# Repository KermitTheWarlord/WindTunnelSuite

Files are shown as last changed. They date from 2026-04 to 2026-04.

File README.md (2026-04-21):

# WindTunnelSuite

Control and monitoring system for a small educational wind tunnel built around **Arduino** and a **Windows Forms PC application**.

This project combines:

- a physical wind tunnel prototype
- Arduino firmware for sensors, fans, lighting, and airfoil-angle control
- a Windows desktop UI for live control and telemetry
- KiCad schematic files
- 3D printed mechanical parts for the enclosure, tunnel sections, venturi iterations, and smoke-flow visualization parts

---

## Project purpose

The goal of this project is to create a **modular and understandable wind tunnel system** suitable for:

- school demonstrations
- basic aerodynamic experiments
- testing airflow behavior around an airfoil
- learning embedded control, sensors, PWM, serial communication, and PC-side visualization

The current implementation is intentionally built at **educational / demonstrational scale**.  
The present fan solution uses **4 smaller fans** as a modular temporary approach, but the design can be adapted later to a **single larger high-flow fan**.

---

## Main features

### Arduino side
- PWM control of multiple fans
- control of airfoil angle through a stepper motor and A4988 driver
- angle feedback with AS5600 magnetic encoder
- barometric pressure and temperature measurement
- differential pressure measurement for airflow-related testing
- serial command parser for communication with the PC app
- telemetry output back to the PC application
- EEPROM storage for encoder zero / home behavior

### PC application side
- serial COM port connection
- separate UI pages for:
  - fan control
  - sensor live data
  - airfoil angle control
- live telemetry parsing
- console log for TX/RX debugging
- visual organization of controls for easy demonstration use

### Mechanical side
- 3D printed wind tunnel body and sections
- two physical design directions / configurations were used during development:
  - larger concept around **540 x 540 mm** inlet class
  - smaller demonstrational configuration around **240 x 240 mm** for use with PC fans
- venturi development through multiple printed variants
- smoke injector and holder for visual airflow observation
- printed enclosure / holder components for electronics and mounting

---

## Repository contents

Typical contents in this repository include:

- Arduino sketch / firmware
- Windows Forms solution
- KiCad schematic files
- schematic export PDF
- 3D model files (`.3mf`)
- supporting documentation and project assets

Important project files include:

- `WTS_Arduino_Sketch.ino` – Arduino firmware
- `WindTunnelSuite.sln` – Visual Studio solution
- `Arduino LED Blinker/WindTunnelSuite.csproj` – WinForms project
- `Arduino LED Blinker/Form1.cs` – main shell / navigation / serial handling
- `Arduino LED Blinker/FansPage.xaml.cs` – fan control page
- `Arduino LED Blinker/SensorsPage.xaml.cs` – live sensor page
- `Arduino LED Blinker/AirfoilAnglePage.cs` – airfoil angle control page
- `Arduino LED Blinker/TelemetryStore.cs` – telemetry parser / storage
- KiCad files for the electrical design
- `.3mf` files for the mechanical parts

---

## Hardware overview

### Main controller
- **Arduino Uno**  
Chosen because it is widely available, easy to program, well documented, and fully adequate for a school-scale control system.

### Sensors
- **AS5600 magnetic encoder**  
Used to measure the real angular position of the airfoil mechanism.

- **MPXV7002 differential pressure sensor**  
Used for airflow / pressure-difference observation in the test section.

- **BMP sensor module**  
The project wiring was prepared so the connector can support a **BMP280-style module**, while the current code path can also work with a **BMP180/BMP085-type module** because only the required **3.3 V, GND, SDA, and SCL** lines are needed in this operating mode.

### Actuators
- **A4988 stepper driver + NEMA 17 stepper motor**  
Used to rotate and position the airfoil.

- **4 fans**  
Used in the current prototype for demonstrational airflow generation. This is a modular starter solution.

- **LED lighting via MOSFET**  
Used for visual illumination of the test area.

### Protection / support components
- fuse on the AC input side
- onboard / supply-side protection
- filter / buffer capacitors
- gate resistor and pull-down resistor for MOSFET-based switching
- common ground strategy for correct signal reference

### Capacitors
Capacitors in the system are used mainly as **parallel filtering and buffering elements** on the supply rails.  
Their role is to:
- reduce voltage dips
- smooth disturbances caused by switching loads
- improve stability when motors, fans, or other loads change state

Examples used in the project documentation:
- **1000 µF / 25 V**
- **100 µF / 25 V**

---

## Electrical connection summary

### I2C bus
The I2C sensor modules are connected **in parallel** to the same:
- SDA line
- SCL line
- 3.3 V supply
- ground

This is normal I2C bus wiring and allows multiple compatible devices on the same bus.

### Fans
The fans are powered as **parallel loads** from the common supply, while their control is handled through PWM-related circuitry / control outputs.

### LED lighting
The LED lighting is treated as a **parallel-powered load** controlled through a MOSFET switching stage.

### AC input path
The AC switch and fuse are connected **in series** in the mains input path so that:
- the switch can disconnect power
- the fuse can interrupt the circuit in fault conditions

### Potentiometer
The potentiometer is used as a **voltage divider**.  
Its output is read by an Arduino analog input and converted into a control value.

---

## Software architecture

### Arduino firmware
The firmware is structured around several responsibilities:

- reading commands from serial
- controlling fans
- controlling the stepper motor
- reading sensors
- outputting telemetry
- managing home / zero logic for the encoder

Typical command ideas used by the PC app include:

- `FAN ALL <value>`
- `FAN 1 <value>`
- `FAN 2 <value>`
- `FAN 3 <value>`
- `FAN 4 <value>`
- `FAN STOP`
- `STEPPER GOTO <steps> <speed>`
- `STEPPER STOP`
- `ENCODER ZERO`

Telemetry is sent back in a compact key-value style so the desktop app can parse and display live values.

### Notes
- In the current development stage, some RPM values shown in the software can be **simulated from PWM percentage** instead of coming from real tachometer feedback.
- Telemetry names may reflect earlier naming choices; for example a field like `mpx_adc` may actually represent a processed pressure-related value in software rather than a raw ADC count.

### Windows Forms application

The desktop software is built with **C# Windows Forms**.

#### Main responsibilities
- connect to Arduino through a COM port
- send user commands
- parse incoming telemetry
- display live values
- show a TX/RX console for debugging

#### Main pages

**Fans page**  
Used to control:
- all fans together
- each fan individually

It also displays RPM-style feedback values for demonstration.

**Sensors page**  
Displays live readings such as:
- last packet received
- fan-related values
- differential pressure
- barometric pressure
- temperature
- encoder angle

**Airfoil Angle page**  
Used to:
- set target angle
- control movement speed
- stop motion
- home the mechanism
- zero the encoder reference

#### UI helper components
A custom `GlassPanel` is used to give the interface a cleaner demonstrational layout.

---

## Libraries

The exact Arduino libraries may depend on the current firmware revision, but the project uses or has used libraries in this area:

- `Wire`
- `EEPROM`
- `AccelStepper`
- Adafruit BMP sensor library path such as:
  - `Adafruit_BMP085` for BMP180/BMP085-style support

Check the `.ino` file for the exact current include list used in the active version.

---

## Real-world testing

The project has been physically tested and documented with:

- real hardware prototype photos
- oscilloscope captures of fan PWM behavior
- fan PWM duty-cycle checks
- sensor checks
- repeated startup / restart behavior
- stepper movement evaluation
- physical airfoil positioning

Oscilloscope photos in the project/documentation correspond to **fan PWM testing** at different duty cycles such as:
- 0%
- 25%
- 50%
- 75%
- 100%

---

## How to build / run

### Arduino
1. Open the Arduino sketch.
2. Install the required libraries.
3. Select the correct board and COM port.
4. Upload the firmware to the Arduino.

### Windows app
1. Open `WindTunnelSuite.sln` in Visual Studio.
2. Build the solution.
3. Run the WinForms application.
4. Select the correct COM port.
5. Connect and begin testing.

---

## Suggested usage flow

1. Power the hardware safely.
2. Connect the Arduino to the PC.
3. Open the Windows application.
4. Select the COM port and connect.
5. Test fan control.
6. Test sensor telemetry.
7. Test airfoil angle movement and zeroing.
8. Observe airflow behavior and, where used, smoke visualization.

---

## Current status

This project is already a **real physical prototype**, not only a theoretical concept.

It includes:
- electrical design
- embedded control
- PC interface
- 3D printed mechanical development
- test measurements
- educational demonstrational functionality

At the same time, it remains open for future upgrades such as:
- larger fan / blower solution
- more accurate airflow measurement
- real tachometer RPM feedback for all fans
- automatic calibration routines
- expanded data logging
- improved aerodynamic measurement accessories

---

## Safety notes

This project includes mains-powered and motor-driven elements.  
Use caution when testing:

- protect AC input properly
- ensure proper insulation
- verify polarity and voltage levels before powering sensors
- do not hot-plug sensitive modules unless the design explicitly supports it
- keep a common ground where required for logic-level reference
- mechanically secure all moving and powered parts

---

## License / usage

This repository was created as part of an engineering / educational diploma project.  
Reuse is possible for learning and experimental purposes, but always verify electrical safety and component suitability for your own build.

---

## Author

**Tony Shivenkov**  
Applied programming diploma project  
Wind tunnel control system

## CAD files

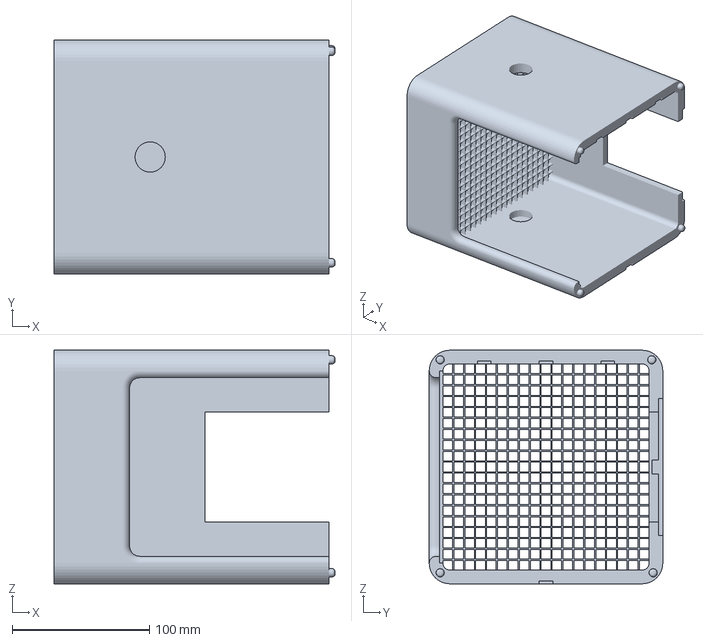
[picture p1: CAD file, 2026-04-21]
3D models/240x240mm tunnel/test_section_2.3mf
204.5 x 170.0 x 170.0 mm

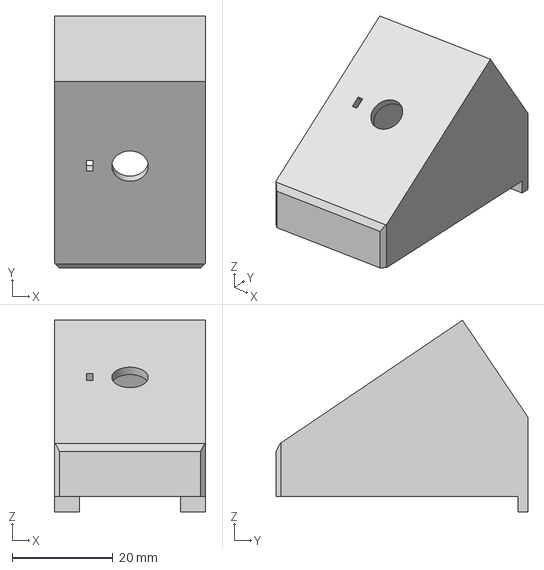
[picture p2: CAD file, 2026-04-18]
3D models/pot holder v2.step
30.0 x 50.0 x 38.0 mm

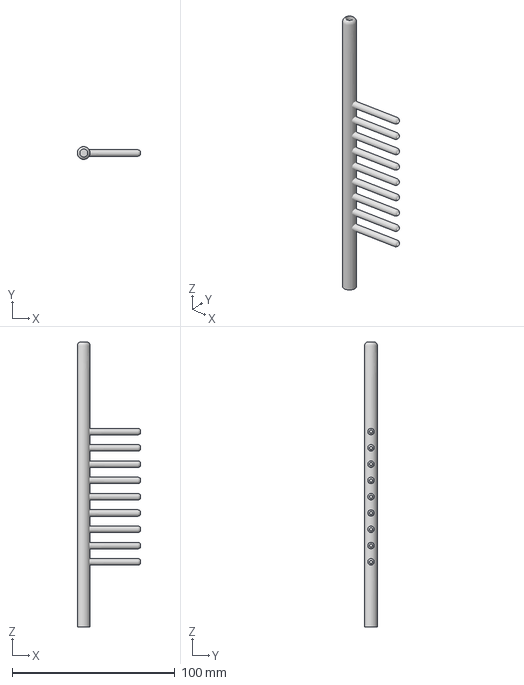
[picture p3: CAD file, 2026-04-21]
3D models/240x240mm tunnel/Smoke injector.3mf
39.0 x 7.89 x 175.0 mm

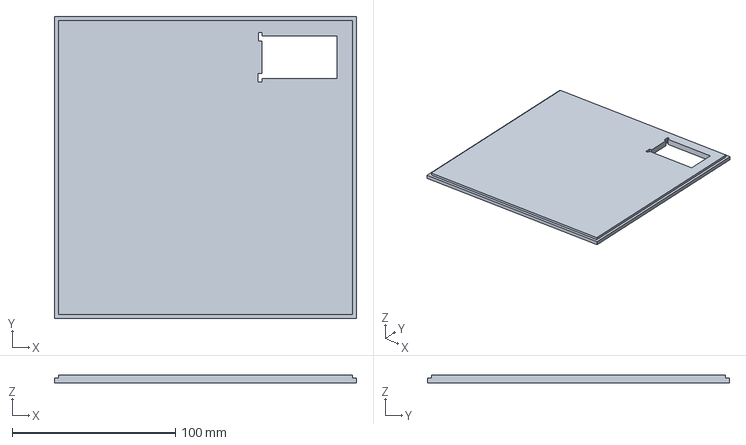
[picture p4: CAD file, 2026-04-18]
3D models/CU_BOX_COVER v2.3mf
185.0 x 185.0 x 5.00 mm

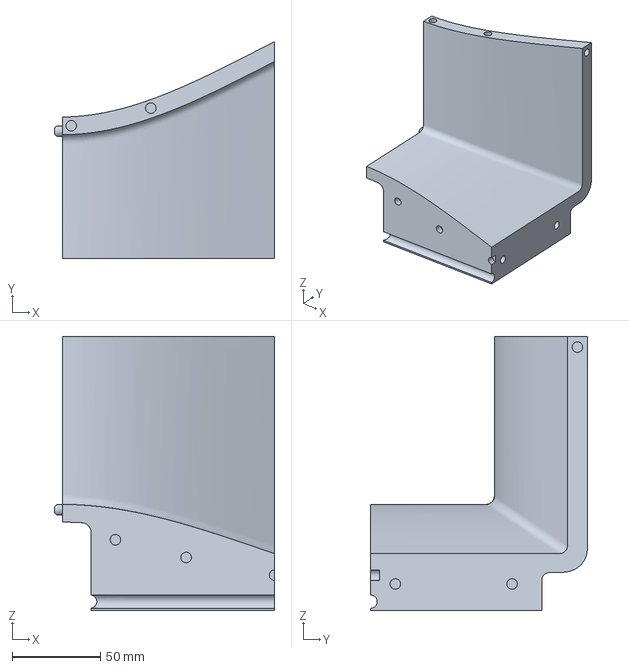
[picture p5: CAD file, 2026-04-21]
3D models/240x240mm tunnel/Ventilator venturi 4.3mf
124.5 x 122.6 x 155.0 mm

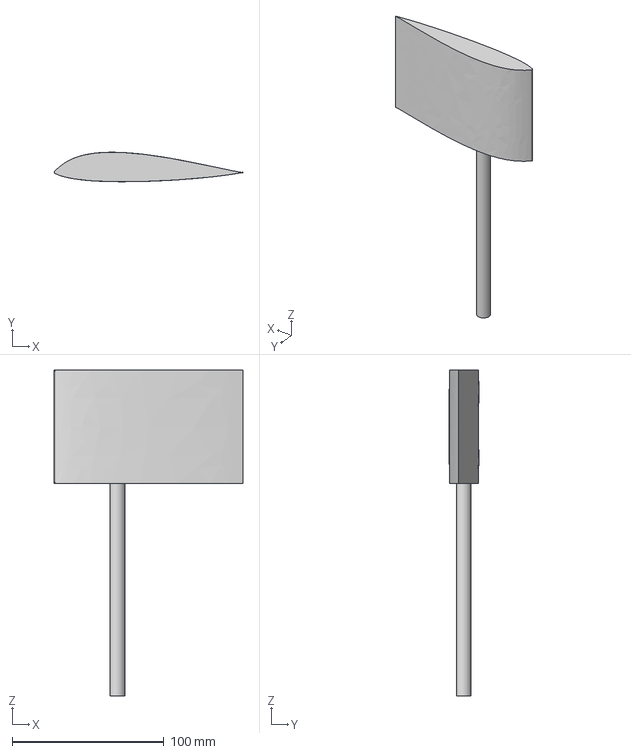
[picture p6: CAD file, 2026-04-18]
3D models/Wing Attachment.step
124.3 x 19.5 x 215.0 mm

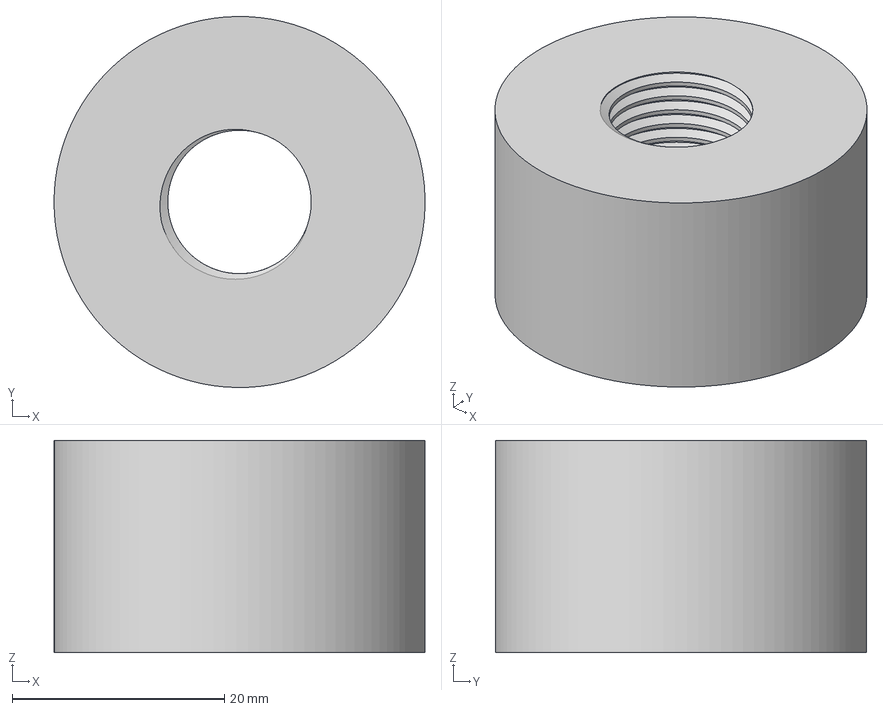
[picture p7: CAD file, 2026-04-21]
3D models/240x240mm tunnel/Smoke Injector holder.3mf
35.0 x 35.0 x 20.0 mm

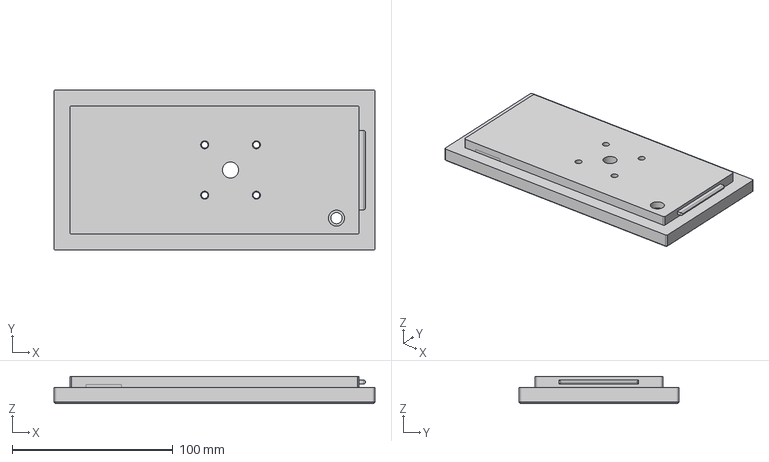
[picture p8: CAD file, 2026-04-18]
3D models/backplate v3.step
200.0 x 100.0 x 17.0 mm

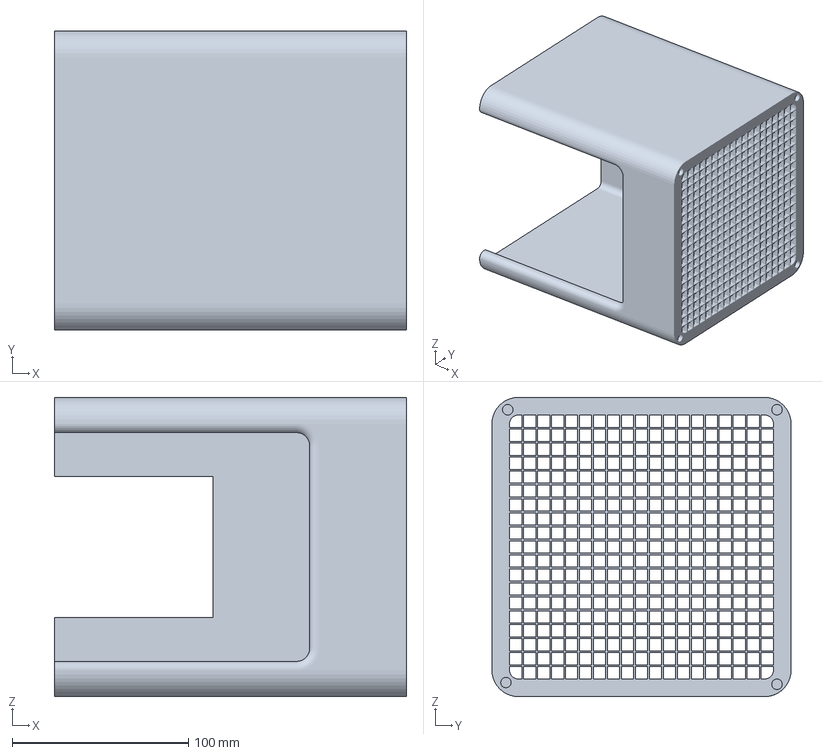
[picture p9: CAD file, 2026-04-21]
3D models/240x240mm tunnel/test_section_1.3mf
200.0 x 170.0 x 170.0 mm

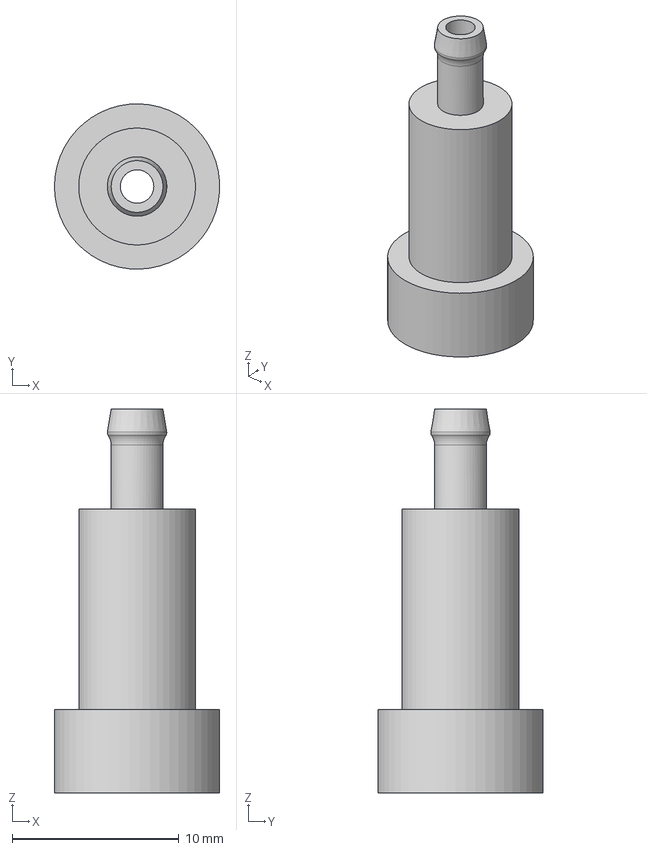
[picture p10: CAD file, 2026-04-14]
3D models/plug for vacuum.step
9.89 x 9.90 x 23.0 mm

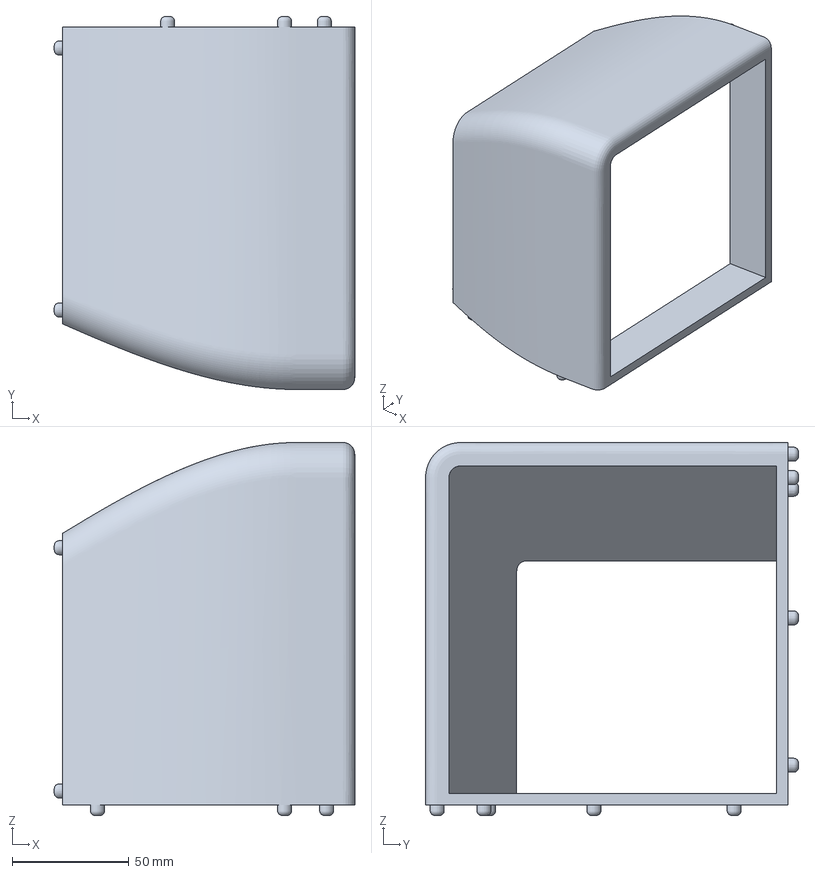
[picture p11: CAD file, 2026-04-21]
3D models/240x240mm tunnel/Ventilator venturi 5.3mf
128.5 x 159.5 x 159.5 mm

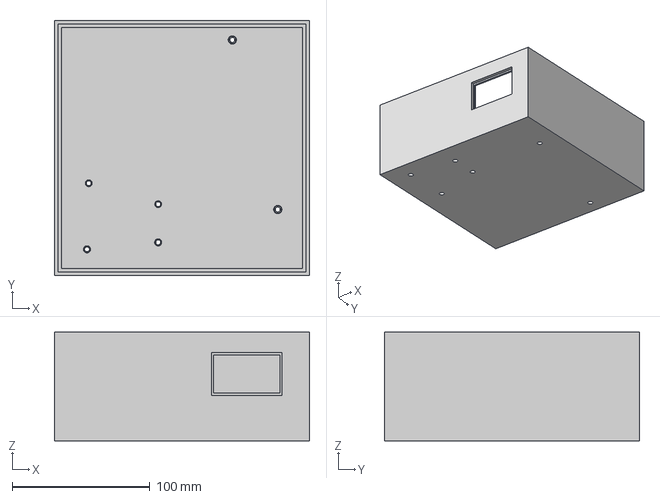
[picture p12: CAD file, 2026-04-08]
3D models/CU BOX v2.step
185.0 x 185.0 x 79.0 mm

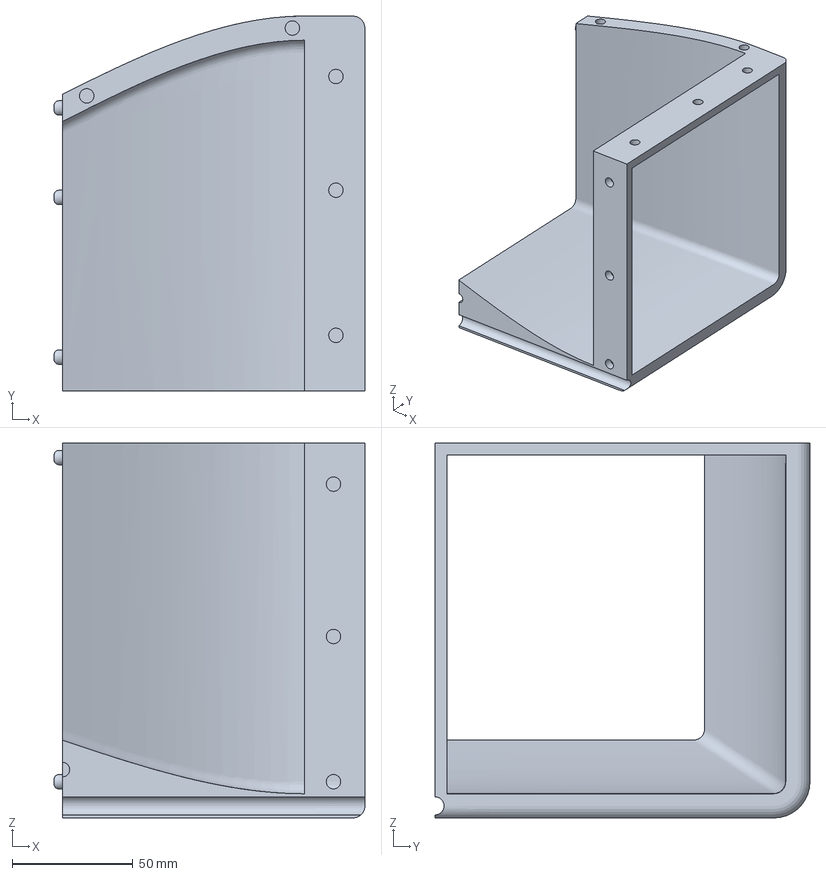
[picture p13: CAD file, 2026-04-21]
3D models/240x240mm tunnel/Ventilator venturi 8.3mf
128.5 x 155.0 x 155.0 mm

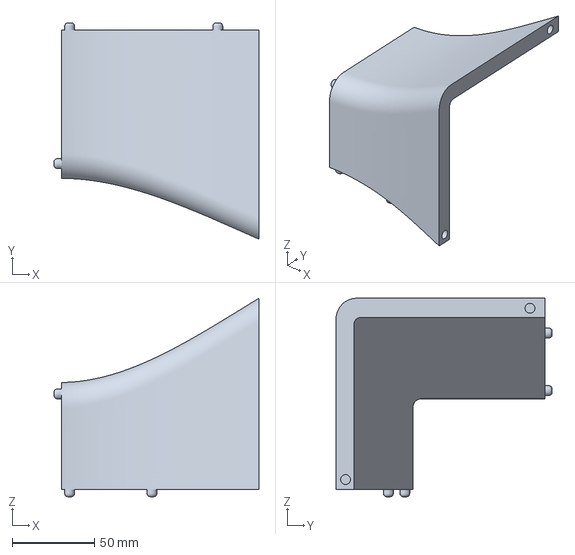
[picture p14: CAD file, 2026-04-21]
3D models/240x240mm tunnel/Ventilator venturi 1.3mf
124.5 x 131.4 x 120.6 mm

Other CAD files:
3D models/240x240mm tunnel/Ventilator venturi 6.3mf
3D models/240x240mm tunnel/Ventilator venturi 3.3mf
3D models/240x240mm tunnel/Ventilator venturi 7.3mf
3D models/240x240mm tunnel/Ventilator venturi 2.3mf

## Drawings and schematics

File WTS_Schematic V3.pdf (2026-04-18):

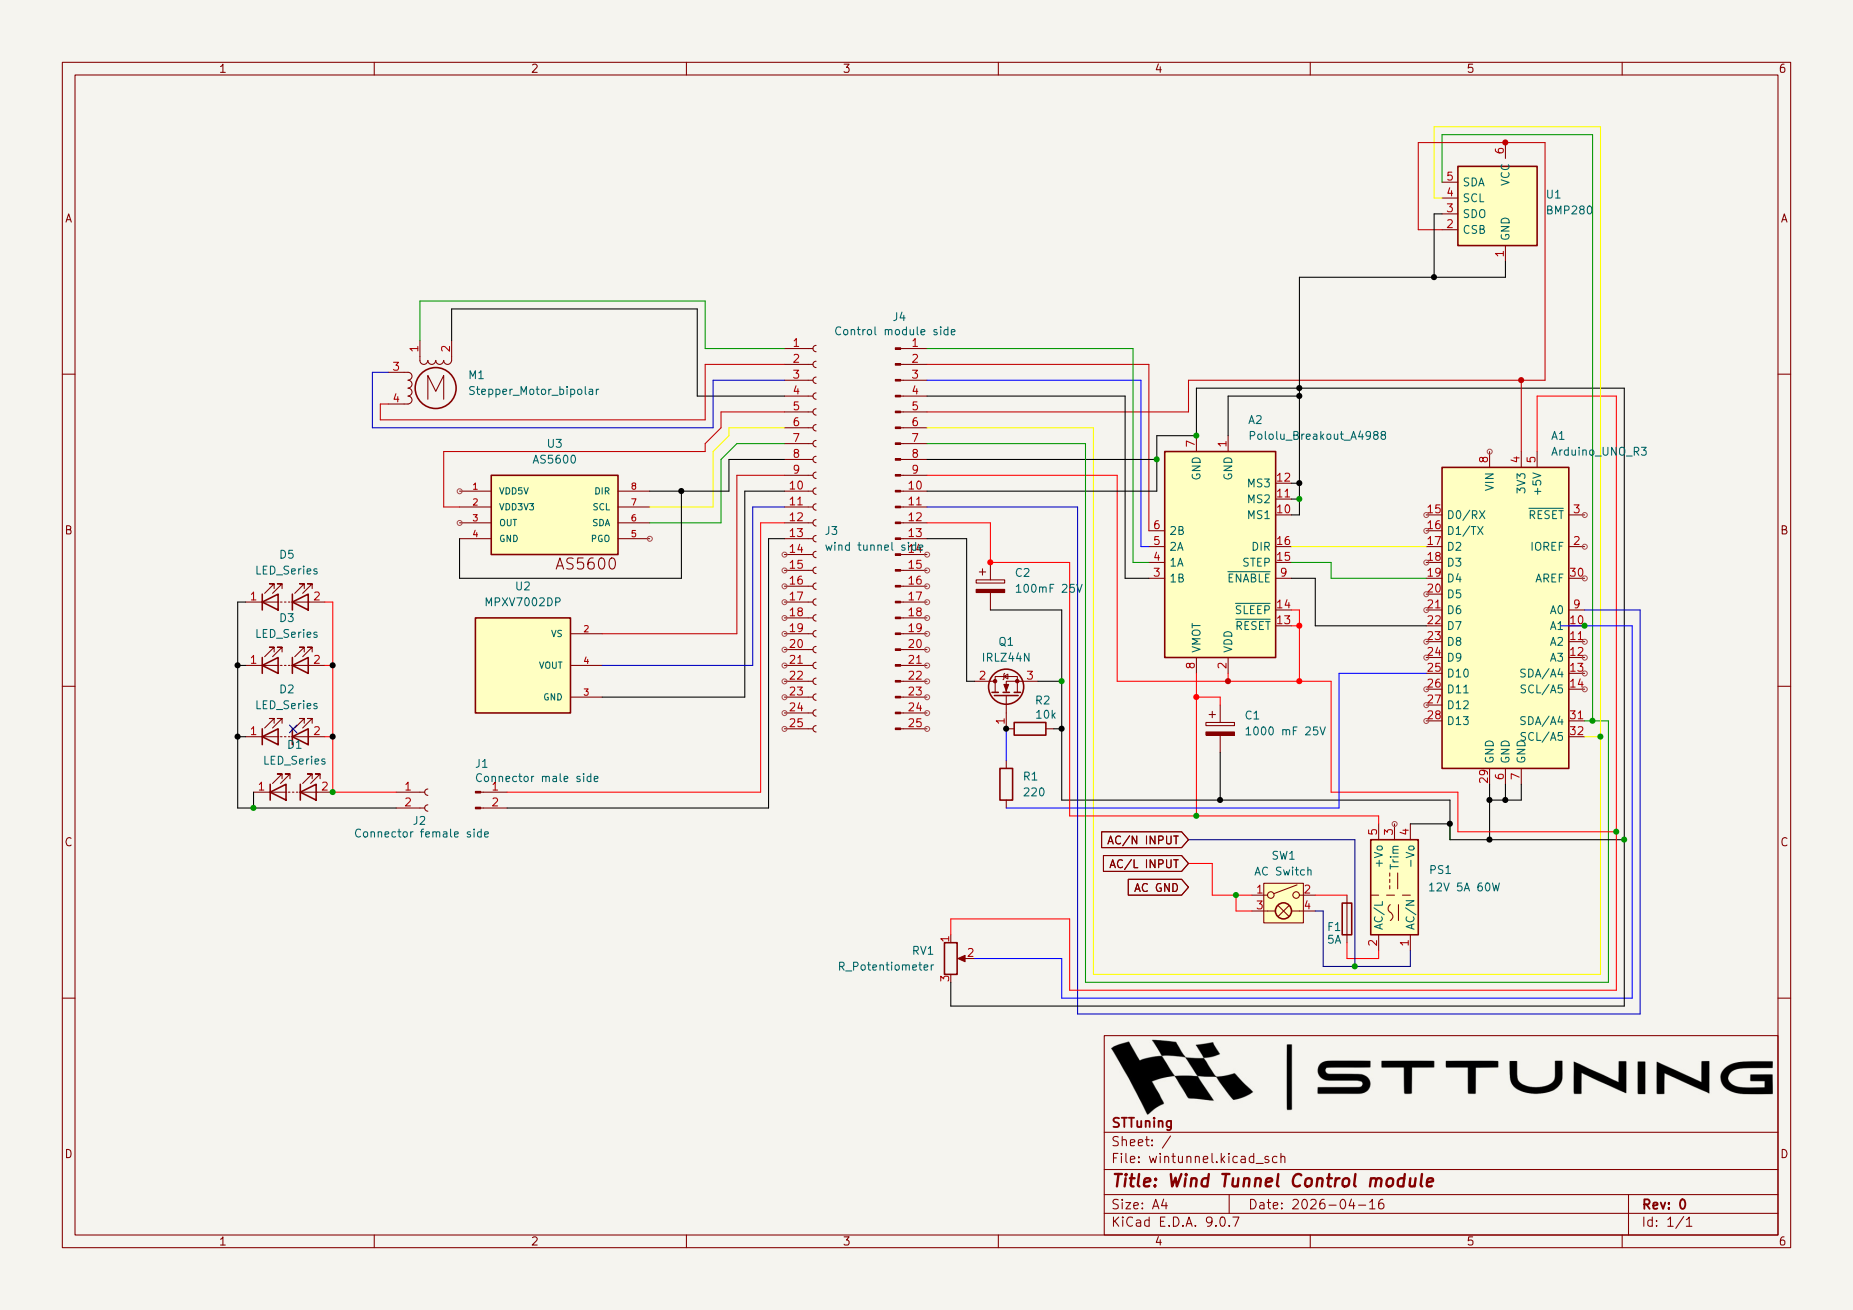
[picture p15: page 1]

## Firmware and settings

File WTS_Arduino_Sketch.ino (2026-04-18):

#include <Wire.h>
#include <Adafruit_BMP085.h>
#include <EEPROM.h>
#include <AccelStepper.h>

#define BAUD 115200

// =====================================================
// BMP180
// =====================================================
Adafruit_BMP085 bmp;
bool bmpOk = false;

// =====================================================
// AS5600
// =====================================================
#define AS5600_ADDR 0x36
bool as5600Ok = false;

// EEPROM storage for encoder zero
const int EEPROM_MAGIC_ADDR = 0;
const int EEPROM_ZERO_ADDR  = 4;
const uint32_t EEPROM_MAGIC = 0xA560BEEF;

float as5600ZeroDeg = 0.0f;
bool as5600ZeroSet = false;

bool as5600Present()
{
  Wire.beginTransmission(AS5600_ADDR);
  return (Wire.endTransmission() == 0);
}

int readAS5600Raw()
{
  Wire.beginTransmission(AS5600_ADDR);
  Wire.write(0x0C);
  if (Wire.endTransmission(false) != 0) return -1;

  Wire.requestFrom(AS5600_ADDR, 2);
  if (Wire.available() < 2) return -1;

  int highByte = Wire.read();
  int lowByte  = Wire.read();

  return ((highByte << 8) | lowByte) & 0x0FFF;
}

float readAS5600Deg()
{
  int raw = readAS5600Raw();
  if (raw < 0) return -999.0f;
  return (raw * 360.0f) / 4096.0f;
}

float normalizeAngle180(float deg)
{
  while (deg > 180.0f) deg -= 360.0f;
  while (deg < -180.0f) deg += 360.0f;
  return deg;
}

float readAS5600SignedDeg()
{
  float rawDeg = readAS5600Deg();
  if (rawDeg < -100.0f) return -999.0f;

  if (!as5600ZeroSet)
    return normalizeAngle180(rawDeg);

  return normalizeAngle180(rawDeg - as5600ZeroDeg);
}

void saveEncoderZeroToEEPROM()
{
  EEPROM.put(EEPROM_MAGIC_ADDR, EEPROM_MAGIC);
  EEPROM.put(EEPROM_ZERO_ADDR, as5600ZeroDeg);
}

void loadEncoderZeroFromEEPROM()
{
  uint32_t magic = 0;
  EEPROM.get(EEPROM_MAGIC_ADDR, magic);

  if (magic == EEPROM_MAGIC)
  {
    EEPROM.get(EEPROM_ZERO_ADDR, as5600ZeroDeg);
    as5600ZeroSet = true;
  }
  else
  {
    as5600ZeroDeg = 0.0f;
    as5600ZeroSet = false;
  }
}

void clearEncoderZeroInEEPROM()
{
  uint32_t zeroMagic = 0;
  EEPROM.put(EEPROM_MAGIC_ADDR, zeroMagic);
  as5600ZeroDeg = 0.0f;
  as5600ZeroSet = false;
}

// =====================================================
// MPXV7002DP
// =====================================================
#define MPX_PIN A0

float readMPXV7002_mbar()
{
  const int samples = 4;
  long sum = 0;
  for (int i = 0; i < samples; i++)
    sum += analogRead(MPX_PIN);

  float adc = sum / (float)samples;
  float voltage = adc * (5.0f / 1023.0f);
  float pressure_kPa = ((voltage / 5.0f) - 0.5f) / 0.2f;
  float pressure_mbar = pressure_kPa * 10.0f;

  return pressure_mbar;
}

// =====================================================
// LED PWM + POT
// =====================================================
#define POT_PIN     A1
#define LED_PWM_PIN 10

int ledPct = 0;
int ledPwm = 0;

void updateLedFromPot()
{
  int potValue = analogRead(POT_PIN);
  ledPwm = map(potValue, 0, 1023, 0, 255);
  ledPct = map(potValue, 0, 1023, 0, 100);
  analogWrite(LED_PWM_PIN, ledPwm);
}

// =====================================================
// FAN SETUP
// =====================================================
const int FAN_PWM_PIN[4] = {3, 5, 6, 9};
int fanPct[4] = {0, 0, 0, 0};
int fanAll = 0;

int clampPct(int v)
{
  if (v < 0) return 0;
  if (v > 100) return 100;
  return v;
}

void setFan(int idx, int pct)
{
  pct = clampPct(pct);
  fanPct[idx] = pct;
  int duty = map(pct, 0, 100, 0, 255);
  analogWrite(FAN_PWM_PIN[idx], duty);
}

void setAllFans(int pct)
{
  pct = clampPct(pct);
  fanAll = pct;
  for (int i = 0; i < 4; i++) setFan(i, pct);
}

// =====================================================
// STEPPER SETUP (AccelStepper)
// Expected hardware for 1/8 microstep:
// MS1 = HIGH, MS2 = HIGH, MS3 = LOW
// =====================================================
#define STEP_DIR_PIN   2
#define STEP_STEP_PIN  4
#define STEP_EN_PIN    7

AccelStepper stepper(AccelStepper::DRIVER, STEP_STEP_PIN, STEP_DIR_PIN);

bool step_enabled = true;
int step_sps = 1200;

// Tune these if needed
const float STEPPER_ACCEL = 2500.0f;   // steps/sec^2
const int STEP_MIN_SPS = 100;
const int STEP_MAX_SPS = 3000;

void stepSetEnable(bool en)
{
  step_enabled = en;
  digitalWrite(STEP_EN_PIN, en ? LOW : HIGH); // A4988 EN active LOW

  if (!en)
    stepper.stop();
}

int clampSps(int v)
{
  if (v < STEP_MIN_SPS) return STEP_MIN_SPS;
  if (v > STEP_MAX_SPS) return STEP_MAX_SPS;
  return v;
}

void stepSetSpeedSps(int sps)
{
  step_sps = clampSps(sps);
  stepper.setMaxSpeed((float)step_sps);
}

void stepStop()
{
  stepper.stop();
}

void stepMoveRelative(long steps, int sps)
{
  if (!step_enabled) return;
  stepSetSpeedSps(sps);
  stepper.move(steps);
}

void stepGotoAbsolute(long pos, int sps)
{
  if (!step_enabled) return;
  stepSetSpeedSps(sps);
  stepper.moveTo(pos);
}

// =====================================================
// COMMAND PARSING
// =====================================================
void handleLine(char* line)
{
  while (*line == ' ' || *line == '\t') line++;
  if (!*line) return;

  if (strcmp(line, "FAN STOP") == 0)
  {
    setAllFans(0);
    Serial.println("OK FAN STOP");
    return;
  }

  {
    char which[8] = {0};
    int pct = 0;

    if (sscanf(line, "FAN %7s %d", which, &pct) == 2)
    {
      if (strcmp(which, "ALL") == 0)
      {
        setAllFans(pct);
        Serial.print("OK FAN ALL ");
        Serial.println(fanAll);
        return;
      }

      int n = atoi(which);
      if (n >= 1 && n <= 4)
      {
        setFan(n - 1, pct);
        Serial.print("OK FAN ");
        Serial.print(n);
        Serial.print(" ");
        Serial.println(clampPct(pct));
        return;
      }
    }
  }

  if (strcmp(line, "STEPPER STOP") == 0)
  {
    stepStop();
    Serial.println("OK STEPPER STOP");
    return;
  }

  {
    int enVal = -1;
    if (sscanf(line, "STEPPER EN %d", &enVal) == 1)
    {
      stepSetEnable(enVal != 0);
      Serial.print("OK STEPPER EN ");
      Serial.println(step_enabled ? 1 : 0);
      return;
    }
  }

  {
    long steps = 0;
    int sps = 0;
    if (sscanf(line, "STEPPER MOVE %ld %d", &steps, &sps) == 2)
    {
      stepMoveRelative(steps, sps);
      Serial.print("OK STEPPER MOVE target=");
      Serial.print(stepper.targetPosition());
      Serial.print(" sps=");
      Serial.println(step_sps);
      return;
    }
  }

  {
    long pos = 0;
    int sps = 0;
    if (sscanf(line, "STEPPER GOTO %ld %d", &pos, &sps) == 2)
    {
      stepGotoAbsolute(pos, sps);
      Serial.print("OK STEPPER GOTO target=");
      Serial.print(stepper.targetPosition());
      Serial.print(" sps=");
      Serial.println(step_sps);
      return;
    }
  }

  if (strcmp(line, "ENCODER ZERO") == 0)
  {
    float rawDeg = readAS5600Deg();
    if (rawDeg < -100.0f)
    {
      Serial.println("ERR ENCODER ZERO");
      return;
    }

    as5600ZeroDeg = rawDeg;
    as5600ZeroSet = true;
    saveEncoderZeroToEEPROM();

    stepper.setCurrentPosition(0);
    stepper.moveTo(0);

    Serial.println("OK ENCODER ZERO");
    return;
  }

  if (strcmp(line, "ENCODER CLEAR") == 0)
  {
    clearEncoderZeroInEEPROM();
    Serial.println("OK ENCODER CLEAR");
    return;
  }

  Serial.print("ERR ");
  Serial.println(line);
}

// =====================================================
// SETUP
// =====================================================
void setup()
{
  Serial.begin(BAUD);
  Wire.begin();

  for (int i = 0; i < 4; i++)
  {
    pinMode(FAN_PWM_PIN[i], OUTPUT);
    analogWrite(FAN_PWM_PIN[i], 0);
  }

  pinMode(MPX_PIN, INPUT);

  pinMode(POT_PIN, INPUT);
  pinMode(LED_PWM_PIN, OUTPUT);
  analogWrite(LED_PWM_PIN, 0);

  pinMode(STEP_EN_PIN, OUTPUT);
  stepSetEnable(true);

  stepper.setMaxSpeed((float)step_sps);
  stepper.setAcceleration(STEPPER_ACCEL);
  stepper.setCurrentPosition(0);

  bmpOk = bmp.begin();
  if (bmpOk) Serial.println("OK BMP180 FOUND");
  else       Serial.println("WARN BMP180 NOT FOUND");

  as5600Ok = as5600Present();
  if (as5600Ok) Serial.println("OK AS5600 FOUND");
  else          Serial.println("WARN AS5600 NOT FOUND");

  loadEncoderZeroFromEEPROM();
  if (as5600ZeroSet) Serial.println("OK ENCODER ZERO LOADED");
  else               Serial.println("WARN ENCODER ZERO NOT SET");

  Serial.println("READY");
}

// =====================================================
// LOOP
// =====================================================
void loop()
{
  // This must run as often as possible
  if (step_enabled)
    stepper.run();

  bool step_moving = (stepper.distanceToGo() != 0);

  if (!step_moving)
    updateLedFromPot();

  static char buf[96];
  static byte idx = 0;

  while (Serial.available())
  {
    char c = Serial.read();
    if (c == '\r') continue;

    if (c == '\n')
    {
      buf[idx] = 0;
      handleLine(buf);
      idx = 0;
    }
    else if (idx < sizeof(buf) - 1)
    {
      buf[idx++] = c;
    }
  }

  static unsigned long last = 0;
  unsigned long now = millis();

  if (!step_moving && (now - last >= 300))
  {
    last = now;

    int rpm1 = fanPct[0] * 40;
    int rpm2 = fanPct[1] * 40;
    int rpm3 = fanPct[2] * 40;
    int rpm4 = fanPct[3] * 40;

    float mpx_mbar = readMPXV7002_mbar();

    float bmp_p = 0.0f;
    float bmp_t = 0.0f;
    if (bmpOk)
    {
      bmp_t = bmp.readTemperature();
      bmp_p = bmp.readPressure() / 100.0f;
    }

    float as5600 = -999.0f;
    if (as5600Ok && as5600Present())
    {
      as5600 = readAS5600SignedDeg();
    }

    Serial.print("T ");
    Serial.print("fanAll="); Serial.print(fanAll);
    Serial.print(" fan1=");  Serial.print(fanPct[0]);
    Serial.print(" fan2=");  Serial.print(fanPct[1]);
    Serial.print(" fan3=");  Serial.print(fanPct[2]);
    Serial.print(" fan4=");  Serial.print(fanPct[3]);

    Serial.print(" rpm1=");  Serial.print(rpm1);
    Serial.print(" rpm2=");  Serial.print(rpm2);
    Serial.print(" rpm3=");  Serial.print(rpm3);
    Serial.print(" rpm4=");  Serial.print(rpm4);

    Serial.print(" mpx_adc="); Serial.print(mpx_mbar, 1);
    Serial.print(" bmp_p=");   Serial.print(bmp_p, 1);
    Serial.print(" bmp_t=");   Serial.print(bmp_t, 1);
    Serial.print(" as5600=");  Serial.print(as5600, 1);
    Serial.print(" led_pct="); Serial.print(ledPct);

    Serial.print(" step_pos=");    Serial.print(stepper.currentPosition());
    Serial.print(" step_target="); Serial.print(stepper.targetPosition());
    Serial.print(" step_en=");     Serial.print(step_enabled ? 1 : 0);
    Serial.print(" step_moving="); Serial.print(step_moving ? 1 : 0);
    Serial.print(" step_sps=");    Serial.println(step_sps);
  }
}

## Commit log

2026-04-06 Arduino code which processes all inputs
    Arduino code which processes all inputs from the windows forms apps, so far stepper motor is functioning, other values are simulated.
    So far confirmed to work:
    NEMA 17 stepper motor controlled by an a4988 stepper driver at 1.7A functioning on full step (ms1,ms2,ms3) are shorted together.
    To be added soon:
    BMP280
    mpxv7200
    PWM Control for normal PC fans
    AS5600 stepper encoder
    [WTS_Arduino_Sketch.ino]
2026-04-06 Integrate BMP180 sensor for temperature and pressure
    Added support for BMP180 sensor readings and initialization.
2026-04-08 Implement AS5600 encoder and EEPROM functionality
    Added AS5600 encoder support with EEPROM storage for zero position. Updated fan and stepper control commands.
2026-04-08 Box which stores all electronics
    [CU BOX v2.step]
2026-04-15 fixed mounting for mpv7002
    [backplate v3.step]
2026-04-15 changed mpx sensor label to show mBar instead of ADC
2026-04-15 Add MPXV7002DP pressure sensor reading function in mBar
2026-04-16 Wiring schematic
2026-04-16 KiCad Schematic file and PDF
    [wintunnel.kicad_sch]
2026-04-17 Implement LED brightness control from potentiometer
    Added PWM LED control functionality based on potentiometer input along with its own telemetry.
2026-04-17 Added elements for pwm control of led lights via potentiometer
    [wintunnel.kicad_sch]
2026-04-17 PDF of schematic
2026-04-17 potentiometer holder
    [pot holder v2.step]
2026-04-17 improved design and fitment
    [backplate v3.step]
2026-04-18 Refactor stepper control using AccelStepper library
2026-04-21 Original project files, more student friendly
    this wind tunnel is split into many smaller parts compatible with smaller printers
    [Smoke Injector holder.3mf, Smoke injector.3mf, Ventilator venturi 1.3mf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]
